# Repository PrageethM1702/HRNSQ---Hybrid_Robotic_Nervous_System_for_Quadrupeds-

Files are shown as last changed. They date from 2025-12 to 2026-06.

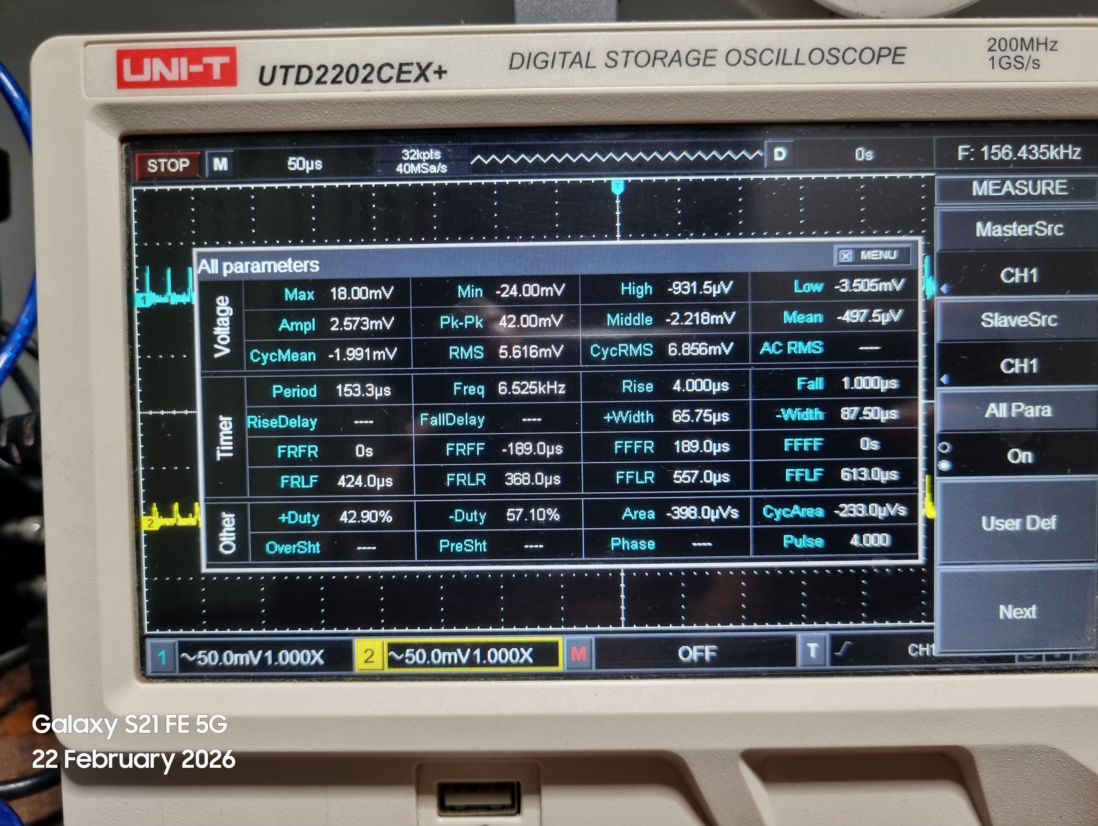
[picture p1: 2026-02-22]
Experimental/FSR Filter/20260222_204912.jpg

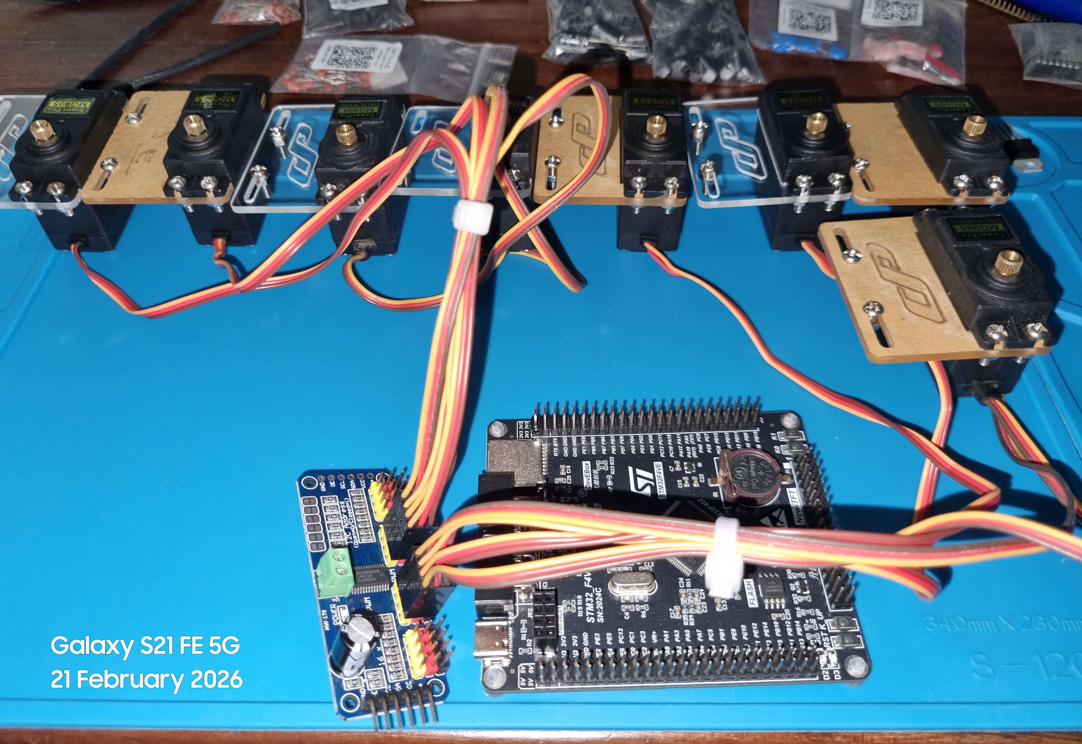
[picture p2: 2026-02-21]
Images/20260221_194545.jpg

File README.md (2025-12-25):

# Hybrid-Robotic-Nervous-System-
Implementation of a Hybrid Robotic Nervous System combining low-level reflex circuits and high-level AI cognition to study adaptive locomotion in quadruped robots.

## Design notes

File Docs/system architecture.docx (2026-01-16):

HRNSQ – Complete System Architecture

1. Mechanical System (Body & Locomotion Hardware)

This is the physical structure.

1.1 Chassis / Frame

- Central body frame (aluminum / acrylic)
- Mounts for:
  - Batteries
  - Control boards
  - Sensors
  - Power distribution
- Vibration isolation mounts

1.2 Leg Mechanism (4 Legs)

Each leg typically:

- 3 DOF (Hip, Thigh, Knee) or 2 DOF depending on design
- Linkages
- Joint brackets
- Bearings & shafts

2. Actuation System (Muscles of the Robot)

This is what moves the robot.

2.1 Primary Actuators

- High-torque servos / BLDC motors / Smart servos
- Per joint: 1 actuator
- Total: usually 12 motors for 3-DOF × 4 legs

2.2 Motor Drivers

- H-bridge drivers (e.g. BTS7960, L298, Cytron)
- ESCs (if BLDC)
- Current sensing drivers (for torque estimation)

3. Power System (Energy & Distribution)

This is the robot’s circulatory system.

3.1 Power Source

- Li-ion / LiPo battery pack
- Voltage level: e.g. 12V / 14.8V / 24V

3.2 Power Regulation

- Buck converters (step-down)
- LDO regulators
- Isolated DC-DC (for sensitive electronics)

3.3 Power Distribution Board (PDB)

- Fused outputs
- Separate rails:
  - Motors
  - Logic
  - Sensors
  - AI compute

3.4 Battery Management

- BMS (overcharge, over-discharge, balancing)
- Voltage monitoring
- Current monitoring

4. Sensing System (Peripheral Nervous System)

This is where your bio-inspired nervous system becomes real.

4.1 Proprioceptive Sensors (Internal State)

- Joint angle sensors
  - Potentiometers
  - Magnetic encoders (AS5600 etc.)
- Motor current sensors (for torque sensing)
- Temperature sensors (motor protection)

4.2 Exteroceptive Sensors (External World)

- Foot pressure sensors
  - FSRs
  - Piezo sensors
- Distance sensors
  - Ultrasonic
  - ToF (VL53L0X etc.)
  - Depth camera setup (esp32 cam)
- Vision sensor
  - Camera (for Vision NN)
- IMU
  - Accelerometer
  - Gyroscope
  - Magnetometer

4.3 Special Bio-Inspired Sensors (Optional but powerful)

- Stretch sensors (muscle analogy)
- Tactile arrays
- Force sensors on joints

5. Reflex System (Spinal Cord Layer)

This is one of your core innovations.

5.1 Hardware Reflex Circuits

- Analog comparators
- Op-amps
- Threshold detectors
- Fast interrupt lines

5.2 Reflex Types

- Withdrawal reflex – pull leg back if high pressure
- Load reflex – stiffen leg under heavy load
- Slip reflex – recover if foot slips
- Obstacle reflex – lift leg higher

These work without AI, directly in hardware or low-level MCU logic.

6. Low-Level Control System (Motor Control Layer)

This is like spinal motor neurons.

  6.1 Microcontrollers
- STM32 - Real-time joint control

6.2 Control Algorithms

- PID control
- Impedance control
- Torque control
- Velocity control

6.3 Real-Time Loop

- Sensor read → control law → motor command
- Runs at high frequency (1–5 kHz)

7. Central Pattern Generator (CPG) System

This is the biological gait generator.

7.1 CPG Network

- Mathematical oscillators
- Phase coupling between legs
- Adjustable frequency & phase

7.2 Gait Types

- Walk
- Trot
- Pace
- Bound
- Crawl

7.3 Modulation Inputs

- From Reflex System
- From AI Decision System

8. AI & Neural Network System (Cognition Layer)

This is your brain layer.

8.1 Gait Control Neural Network

- Learning optimal gait patterns
- Fine-tunes CPG parameters
- Trained via RL in simulation

8.2 Sensor Fusion Neural Network

- Inputs:
  - FSR
  - IMU
  - Joint sensors
  - Vision (optional)
- Outputs:
  - Stability estimate
  - Terrain type

8.3 Reflex Modulation Neural Network

- Modulates reflex strength
- Learns when to allow / suppress reflexes

8.4 Vision Neural Network

- Terrain classification
- Obstacle detection
- Depth estimation (if stereo / monocular depth)

8.5 Decision-Making Neural Network

- High-level behavior:
  - Walk
  - Stop
  - Turn
  - Avoid
  - Climb
- Reinforcement learning based

9. High-Level Cognitive System

This is the prefrontal cortex equivalent.

9.1 Behavior Planner

- Finite State Machine (FSM)
- Behavior Trees
- Or RL policy

9.2 Task Layer

- Navigation
- Exploration
- Goal reaching

10. Perception System

This is how the robot understands the world.

10.1 Vision Processing

- OpenCV pipeline
- CNN-based detection
- Optical flow (optional)

10.2 Terrain Analysis

- Flat
- Rough
- Slippery
- Inclined

10.3 Obstacle Mapping

- Local map
- Height map

11. Localization & Navigation System

For future expansion.

11.1 Localization

- Visual odometry
- IMU fusion
- GPS (outdoor)

11.2 SLAM

- Visual SLAM
- Lidar SLAM (future)
- Mapping + localization

12. Communication System

Nervous system communication lines.

12.1 Internal Communication

- I2C
- SPI
- UART
- CAN bus (recommended for robustness)

12.2 External Communication

- WiFi
- Bluetooth
- USB
- Telemetry link

13. Software System

The digital nervous system.

13.1 Operating Framework

- ROS / ROS2
- Custom RTOS

13.2 Modules

- Sensor drivers
- Motor drivers
- AI inference nodes
- Reflex nodes
- CPG node
- Decision node

14. Simulation & Training System

Critical for your project.

14.1 Physics Simulation

- Gazebo
- PyBullet
- Isaac Gym

14.2 AI Training

- PyTorch
- TensorFlow
- Reinforcement Learning frameworks

14.3 Sim-to-Real Transfer

- Domain randomization
- Noise injection

15. Safety & Protection System

Often forgotten but very important.

15.1 Hardware Safety

- Fuses
- Thermal protection
- Emergency stop

15.2 Software Safety

- Watchdog timers
- Fault detection
- Safe shutdown

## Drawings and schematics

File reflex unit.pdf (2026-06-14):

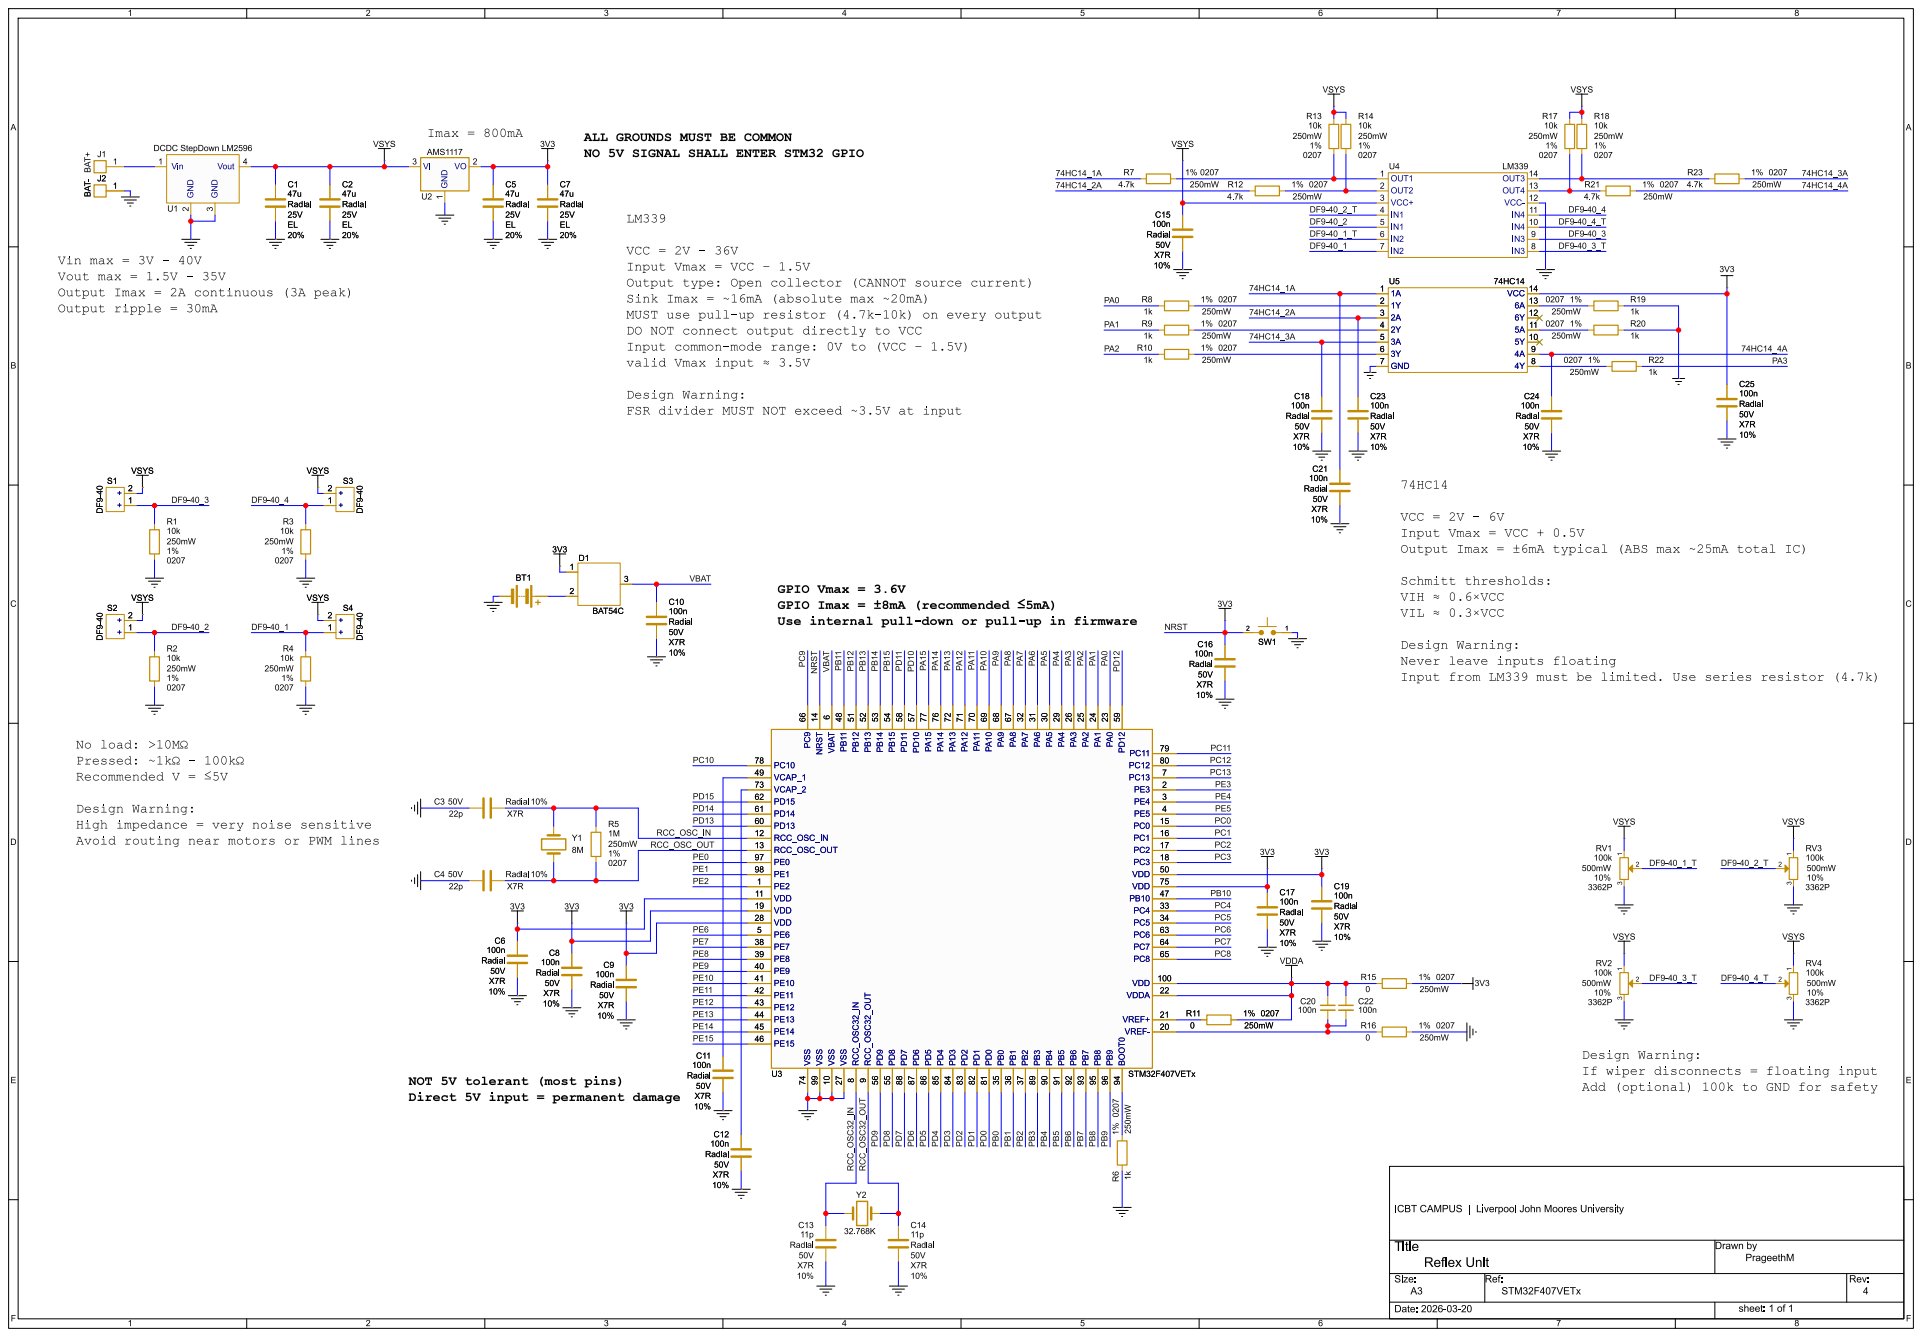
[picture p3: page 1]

ALL GROUNDSMUST BE COMMON
NO 5V SIGNAL SHALL ENTER STM32 GPIO

VCC = 2V - 36V
Input Vmax = VCC þÿ"1.5V
Input common-mode range: 0V to (VCC þÿ"1.5V)

GPIO Vmax = 3.6V
GPIO Imax = þÿ±8mA (recommended þÿ"d5mA)

Design Warning:
High impedance = very noise sensitive

Direct 5V input = permanent damage

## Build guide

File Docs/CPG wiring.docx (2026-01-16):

# HRNSQ Full Wiring Table Analog CPG + Digital Modulation + EMI/Filters (All 4 Legs)

Prageeth Madushankha

# Overview

Front & Rear leg pairs — 2 half-center oscillators, 4 neurons total

# Analog CPG — Neuron A (Front Left / Right)

# | Component | From Pin / Terminal | To Component | To Pin / Terminal | Function

1 | TL072 (Neuron A) | Pin 3 (IN+) | FSR divider output | Vout | Sensory bias input
2 | TL072 (Neuron A) | Pin 2 (IN−) | Inhibition resistor (47 k Ω ) | Junction | Mutual inhibition
3 | Resistor 47 k Ω | One end | TL072 (Neuron B) | Pin 6 (OUT) | Cross inhibition
4 | Resistor 47 k Ω | Other end | TL072 (Neuron A) | Pin 2 (IN−) | Inhibitory input
5 | TL072 (Neuron A) | Pin 6 (OUT) | Timing capacitor (1 μ F) | One terminal | Oscillation timing
6 | Timing capacitor 1 μ F | Other terminal | Ground | GND | RC timing
7 | Resistor 22 k Ω | One end | +Vref | Bias | Threshold set
8 | Resistor 22 k Ω | Other end | TL072 (Neuron A) | Pin 3 (IN+) | Threshold set
9 | Potentiometer 50 k Ω | End terminal | TL072 (Neuron A) | Pin 2 (IN−) | Frequency tuning
10 | Potentiometer 50 k Ω | Wiper | TL072 (Neuron A) | Pin 6 (OUT) | Feedback control
11 | TL072 (Neuron A) | Pin 4 (VCC−) | Power supply | −12V / VGND | Negative rail
12 | TL072 (Neuron A) | Pin 7 (VCC+) | Power supply | +12V | Positive rail
13 | Bypass capacitor 0.1 μ F | One end | Pin 7 | Supply decoupling | High-frequency decoupling
14 | Bypass capacitor 0.1 μ F | Other end | GND | Noise suppression | EMI reduction
15 | Ceramic capacitor 10 nF | Across supply rails | VCC+ / VCC− | Filter | EMI suppression
16 | Ferrite bead | +12V input | TL072 supply | Filter | High-frequency EMI attenuation

Component count (Neuron A): TL072 ×1 , Resistors ×3 , Potentiometer ×1 , Capacitors ×4 , Ferrite bead ×1 .

# Analog CPG — Neuron B (Front Left / Right)

# | Component | From Pin / Terminal | To Component | To Pin / Terminal | Function

17 | TL072 (Neuron B) | Pin 3 (IN+) | FSR divider output | Vout | Sensory bias input
18 | TL072 (Neuron B) | Pin 2 (IN−) | Inhibition resistor (47 k Ω ) | Junction | Mutual inhibition
19 | Resistor 47 k Ω | One end | TL072 (Neuron A) | Pin 6 (OUT) | Cross inhibition
20 | Resistor 47 k Ω | Other end | TL072 (Neuron B) | Pin 2 (IN−) | Inhibitory input
21 | TL072 (Neuron B) | Pin 6 (OUT) | Timing capacitor (1 μ F) | One terminal | Oscillation
22 | Timing capacitor 1 μ F | Other terminal | Ground | GND | RC timing
23 | Resistor 22 k Ω | One end | +Vref | Bias | Threshold set
24 | Resistor 22 k Ω | Other end | TL072 (Neuron B) | Pin 3 (IN+) | Threshold set
25 | Potentiometer 50 k Ω | End terminal | TL072 (Neuron B) | Pin 2 (IN−) | Frequency tuning
26 | Potentiometer 50 k Ω | Wiper | TL072 (Neuron B) | Pin 6 (OUT) | Feedback
27 | Diode 1N4148 | Anode | TL072 (Neuron B) | Pin 6 (OUT) | Amplitude limiting
28 | Diode 1N4148 | Cathode | Ground | GND | Protection
29 | TL072 (Neuron B) | Pin 4 (VCC−) | −12V / VGND | Power
30 | TL072 (Neuron B) | Pin 7 (VCC+) | +12V | Power
31 | Bypass capacitor 0.1 μ F | One end | Pin 7 | Supply decoupling | Noise suppression
32 | Bypass capacitor 0.1 μ F | Other end | GND | Noise suppression | EMI reduction
33 | Ceramic capacitor 10 nF | Across supply rails | VCC+ / VCC− | Filter | EMI suppression
34 | Ferrite bead | +12V input | TL072 supply | Filter | High-frequency EMI attenuation

Component count (Neuron B): TL072 ×1 , Resistors ×3 , Potentiometer ×1 , Capacitors ×4 , Diodes ×2 , Ferrite bead ×1 .

# Analog CPG — Neuron C (Rear Left / Right)

# | Component | From Pin / Terminal | To Component | To Pin / Terminal | Function

41 | TL072 (Neuron C) | Pin 3 (IN+) | FSR divider output | Vout | Sensory bias input
42 | TL072 (Neuron C) | Pin 2 (IN−) | Inhibition resistor (47 k Ω ) | Junction | Mutual inhibition
43 | Resistor 47 k Ω | One end | TL072 (Neuron D) | Pin 6 (OUT) | Cross inhibition
44 | Resistor 47 k Ω | Other end | TL072 (Neuron C) | Pin 2 (IN−) | Inhibitory input
45 | TL072 (Neuron C) | Pin 6 (OUT) | Timing capacitor (1 μ F) | One terminal | Oscillation timing
46 | Timing capacitor 1 μ F | Other terminal | Ground | GND | RC timing
47 | Resistor 22 k Ω | One end | +Vref | Bias | Threshold set
48 | Resistor 22 k Ω | Other end | TL072 (Neuron C) | Pin 3 (IN+) | Threshold set
49 | Potentiometer 50 k Ω | End terminal | TL072 (Neuron C) | Pin 2 (IN−) | Frequency tuning
50 | Potentiometer 50 k Ω | Wiper | TL072 (Neuron C) | Pin 6 (OUT) | Feedback control
51 | TL072 (Neuron C) | Pin 4 (VCC−) | Power supply | −12V / VGND | Negative rail
52 | TL072 (Neuron C) | Pin 7 (VCC+) | Power supply | +12V | Positive rail
53 | Bypass capacitor 0.1 μ F | One end | Pin 7 | Supply decoupling | High-frequency decoupling
54 | Bypass capacitor 0.1 μ F | Other end | GND | Noise suppression | EMI reduction
55 | Ceramic capacitor 10 nF | Across supply rails | VCC+ / VCC− | Filter | EMI suppression
56 | Ferrite bead | +12V input | TL072 supply | Filter | High-frequency EMI attenuation

Component count (Neuron C): TL072 ×1 , Resistors ×3 , Potentiometer ×1 , Capacitors ×4 , Ferrite bead ×1 .

# Analog CPG — Neuron D (Rear Left / Right)

# | Component | From Pin / Terminal | To Component | To Pin / Terminal | Function

57 | TL072 (Neuron D) | Pin 3 (IN+) | FSR divider output | Vout | Sensory bias input
58 | TL072 (Neuron D) | Pin 2 (IN−) | Inhibition resistor (47 k Ω ) | Junction | Mutual inhibition
59 | Resistor 47 k Ω | One end | TL072 (Neuron C) | Pin 6 (OUT) | Cross inhibition
60 | Resistor 47 k Ω | Other end | TL072 (Neuron D) | Pin 2 (IN−) | Inhibitory input
61 | TL072 (Neuron D) | Pin 6 (OUT) | Timing capacitor (1 μ F) | One terminal | Oscillation
62 | Timing capacitor 1 μ F | Other terminal | Ground | GND | RC timing
63 | Resistor 22 k Ω | One end | +Vref | Bias | Threshold set
64 | Resistor 22 k Ω | Other end | TL072 (Neuron D) | Pin 3 (IN+) | Threshold set
65 | Potentiometer 50 k Ω | End terminal | TL072 (Neuron D) | Pin 2 (IN−) | Frequency tuning
66 | Potentiometer 50 k Ω | Wiper | TL072 (Neuron D) | Pin 6 (OUT) | Feedback
67 | Diode 1N4148 | Anode | TL072 (Neuron D) | Pin 6 (OUT) | Amplitude limiting
68 | Diode 1N4148 | Cathode | Ground | GND | Protection
69 | TL072 (Neuron D) | Pin 4 (VCC−) | −12V / VGND | Power
70 | TL072 (Neuron D) | Pin 7 (VCC+) | +12V | Power
71 | Bypass capacitor 0.1 μ F | One end | Pin 7 | Supply decoupling | Noise suppression
72 | Bypass capacitor 0.1 μ F | Other end | GND | Noise suppression | EMI reduction
73 | Ceramic capacitor 10 nF | Across supply rails | VCC+ / VCC− | Filter | EMI suppression
74 | Ferrite bead | +12V input | TL072 supply | Filter | High-frequency EMI attenuation

Component count (Neuron D): TL072 ×1 , Resistors ×3 , Potentiometer ×1 , Capacitors ×4 , Diodes ×2 , Ferrite bead ×1 .

# FSR Sensor Interface (All Legs)

# | Component | From | To | Function

75 | FSR (Front Left) | One terminal | +5V | Force sensing
76 | FSR (Front Left) | Other terminal | Divider resistor (22 k Ω ) | Voltage divider
77 | FSR (Rear Left) | One terminal | +5V | Force sensing
78 | FSR (Rear Left) | Other terminal | Divider resistor (22 k Ω ) | Voltage divider
79 | Resistors 22 k Ω | Other end | GND | Convert force → voltage
80 | Divider output | Junction | TL072 IN+ | Reflex modulation

Component count: FSR ×4 , Resistors ×4 .

# Digital Modulation (Cognitive Layer)

# | Component | From | To | Function

81 | Microcontroller | SDA / SCL | DAC | Digital control
82 | DAC | Analog OUT | Resistor 10 k Ω | Signal conditioning
83 | Resistor 10 k Ω | Other end | TL072 IN+ | Modulation input
84 | Capacitor 100 nF | Across DAC output | GND | EMI filtering
85 | Ferrite bead | DAC supply | TL072 supply | High-frequency EMI

Component count: Microcontroller ×1 , DAC ×1 , Resistors ×1 , Capacitor ×1 , Ferrite bead ×1 .

# Actuation & Power (All Legs)

# | Component | From | To | Function

86 | Motor driver FL | Control | TL072 OUT (A/B) | Front Left / Right actuation
87 | Motor driver RL | Control | TL072 OUT (C/D) | Rear Left / Right actuation
88 | Motor driver | Output | Servo / Motor | Physical movement
89 | Power supply | +12V | TL072 Pin 7 | Analog rail
90 | Power supply | −12V | TL072 Pin 4 | Analog rail
91 | Bypass capacitor 1 μ F | Across rails | +12V / −12V | Power decoupling
92 | Ceramic capacitor 100 nF | Across rails | +12V / −12V | EMI suppression
93 | Ferrite bead | +12V input | Motor driver | EMI suppression

Component count: Motor driver ×2 , Power supply ×1 , Capacitors ×2 , Ferrite bead ×1 .

# Total Component Count (All 4 Legs)

Component | Quantity
TL072 | 4
Resistors | 26
Potentiometers | 4
Capacitors | 22
Diodes | 4
Ferrite beads | 4
FSR | 4
DAC | 1
Microcontroller | 1
Motor drivers | 2

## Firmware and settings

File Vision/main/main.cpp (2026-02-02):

#include <stdio.h>
#include <string.h>

#include "freertos/FreeRTOS.h"
#include "freertos/task.h"

#include "esp_log.h"
#include "esp_system.h"
#include "esp_event.h"
#include "esp_wifi.h"
#include "nvs_flash.h"

#include "esp_http_server.h"
#include "esp_camera.h"
#include "lwip/err.h"
#include "lwip/sys.h"

static const char *TAG = "ESP32_CAM";

/*CAMERA PINS (AI-Thinker / RHYX-M21-45)*/
#define PWDN_GPIO_NUM     32
#define RESET_GPIO_NUM    -1
#define XCLK_GPIO_NUM      0
#define SIOD_GPIO_NUM     26
#define SIOC_GPIO_NUM     27

#define Y9_GPIO_NUM       35
#define Y8_GPIO_NUM       34
#define Y7_GPIO_NUM       39
#define Y6_GPIO_NUM       36
#define Y5_GPIO_NUM       21
#define Y4_GPIO_NUM       19
#define Y3_GPIO_NUM       18
#define Y2_GPIO_NUM        5

#define VSYNC_GPIO_NUM    25
#define HREF_GPIO_NUM     23
#define PCLK_GPIO_NUM     22

#define WIFI_SSID "****"
#define WIFI_PASS "****"

#define PART_BOUNDARY "frame"
static const char* STREAM_CONTENT_TYPE =
    "multipart/x-mixed-replace;boundary=" PART_BOUNDARY;
static const char* STREAM_BOUNDARY = "\r\n--" PART_BOUNDARY "\r\n";
static const char* STREAM_PART =
    "Content-Type: image/jpeg\r\nContent-Length: %u\r\n\r\n";

static esp_err_t stream_handler(httpd_req_t *req)
{
    camera_fb_t *fb;
    char header[64];

    httpd_resp_set_type(req, STREAM_CONTENT_TYPE);

    while (true) {
        fb = esp_camera_fb_get();
        if (!fb) continue;

        httpd_resp_send_chunk(req, STREAM_BOUNDARY, strlen(STREAM_BOUNDARY));
        int len = snprintf(header, sizeof(header), STREAM_PART, fb->len);
        httpd_resp_send_chunk(req, header, len);
        httpd_resp_send_chunk(req, (const char *)fb->buf, fb->len);

        esp_camera_fb_return(fb);
    }
    return ESP_OK;
}

static httpd_handle_t start_webserver(void)
{
    httpd_config_t config = HTTPD_DEFAULT_CONFIG();
    config.server_port = 80;
    config.max_open_sockets = 1;   // FPS boost

    httpd_handle_t server = NULL;
    httpd_start(&server, &config);

    httpd_uri_t stream_uri = {
        .uri = "/stream",
        .method = HTTP_GET,
        .handler = stream_handler
    };
    httpd_register_uri_handler(server, &stream_uri);
    return server;
}

static void wifi_init(void)
{
    esp_netif_init();
    esp_event_loop_create_default();
    esp_netif_create_default_wifi_sta();

    wifi_init_config_t cfg = WIFI_INIT_CONFIG_DEFAULT();
    esp_wifi_init(&cfg);

    wifi_config_t wifi_config = {};
    strcpy((char*)wifi_config.sta.ssid, WIFI_SSID);
    strcpy((char*)wifi_config.sta.password, WIFI_PASS);

    esp_wifi_set_mode(WIFI_MODE_STA);
    esp_wifi_set_config(WIFI_IF_STA, &wifi_config);
    esp_wifi_start();
    esp_wifi_connect();
}

static void camera_init(void)
{
    camera_config_t config = {};
    config.ledc_channel = LEDC_CHANNEL_0;
    config.ledc_timer   = LEDC_TIMER_0;

    config.pin_d0 = Y2_GPIO_NUM;
    config.pin_d1 = Y3_GPIO_NUM;
    config.pin_d2 = Y4_GPIO_NUM;
    config.pin_d3 = Y5_GPIO_NUM;
    config.pin_d4 = Y6_GPIO_NUM;
    config.pin_d5 = Y7_GPIO_NUM;
    config.pin_d6 = Y8_GPIO_NUM;
    config.pin_d7 = Y9_GPIO_NUM;

    config.pin_xclk = XCLK_GPIO_NUM;
    config.pin_pclk = PCLK_GPIO_NUM;
    config.pin_vsync = VSYNC_GPIO_NUM;
    config.pin_href = HREF_GPIO_NUM;
    config.pin_sccb_sda = SIOD_GPIO_NUM;
    config.pin_sccb_scl = SIOC_GPIO_NUM;
    config.pin_pwdn = PWDN_GPIO_NUM;
    config.pin_reset = RESET_GPIO_NUM;

    config.xclk_freq_hz = 20000000;
    config.pixel_format = PIXFORMAT_JPEG;
    config.frame_size = FRAMESIZE_QVGA;
    config.jpeg_quality = 10;
    config.fb_count = 2;

    esp_camera_init(&config);
}


extern "C" void app_main(void)
{
    esp_log_level_set("*", ESP_LOG_ERROR);  

    nvs_flash_init();
    wifi_init();
    camera_init();
    start_webserver();
}

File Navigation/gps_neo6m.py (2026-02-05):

import serial
import pynmea2
import time

# Baud rate for NEO-6M is 9600
# /dev/serial0 points to GPIO 14/15 (UART)
ser = serial.Serial("/dev/serial0", baudrate=9600, timeout = 1)

def read_gps():
    try:
        line = ser.readline().decode('ascii', errors = 'replace')
        if line.startswith('$GPGGA') or line.startswith('$GPRMC'):
            msg = pynmea2.parse(line)
            data = {
                "latitude": msg.latitude,
                "longitude": msg.longitude,
                "timestamp": msg.timestamp if hasattr(msg, "timestamp") else None,
                "altitude": getattr(msg, "altitude", None),
                "num_sats": getattr(msg, "num_sats", None)
            }
            return data
    except pynmea2.ParseError:
        return None
    return None

if __name__ == "__main__":
    while True:
        gps_data = read_gps()
        if gps_data:
            print(f"GPS Data: {gps_data}")
        else:
            print("Waiting for GPS fix...")
        time.sleep(1)

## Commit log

2026-01-26 ESP32 camera streaming functionality
2026-01-26 Modify baseline and focal length for calibration
    Updated baseline and focal length values to placeholders for calibration.
2026-01-27 imu_gy801 unit connected to raspberry pi 3B+
    Nine-Axis Module (three-axis gyroscope + triaxial accelerometer + 3-axis magnetic field + pressure)
    Model: GY-801
    Using a Chip: L3G4200D + ADXL345 + HMC5883L + BMP180
    Power supply: 3-5v
    Communication: IIC communication protocol (fully compatible with 3-5 V system)
    Module size: 25.8mm X 16.8mm, mounting holes 3mm
2026-01-31 Refactor ESP32-CAM stream handling and configuration
    Updated the ESP32-CAM streaming code to improve performance and configuration.
2026-02-02 ESP32 camera initialization and streaming server
    This file initializes an ESP32 camera, sets up Wi-Fi and starts a web server to stream camera images.
2026-02-02 drivers folder
2026-02-02 low level control for servo drivers and sensors
2026-02-03 MLX90614 temperature sensor test script
2026-02-05 SGP30 sensor reading functionality
2026-02-05 si7021 read temperature and humidity
2026-02-09 Add SafeShutdown module to safely disable actuators and power during faults or watchdog triggers
2026-02-11 sensors , gps and supply boards
2026-02-14 Create I2C scan script for sensors
2026-02-15 Reflex Circuit - one single neuron
2026-02-16 reflex circuit fully wired
2026-02-17 Implement power monitoring functions
2026-02-20 bulk decoupling board
    For,
    STM32 board, 2 x esp32 cams
    [power Unit.kicad_sch]
2026-02-21 Servo hat
2026-02-21 RC filter circuit for FSR sensors / Experimental
2026-02-22 Circuit 2 readings from CH1 on the oscilloscope
2026-02-24 Rpi camera and single point LiDAR
